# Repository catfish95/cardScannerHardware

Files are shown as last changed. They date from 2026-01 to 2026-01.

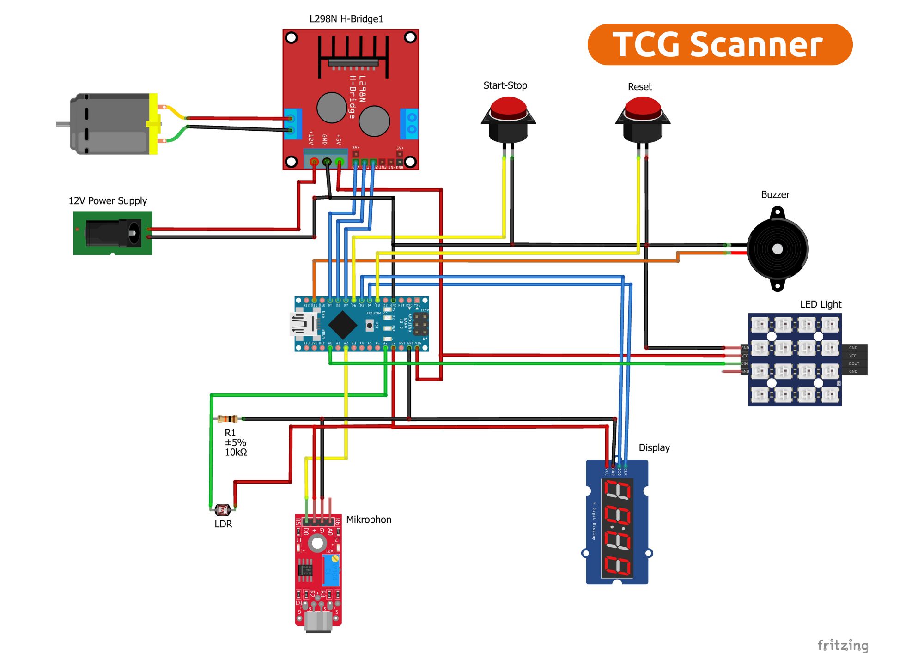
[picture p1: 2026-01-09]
scanner/TCGScanner/Electronics/Wiring diagram - TCG Scanner.jpg

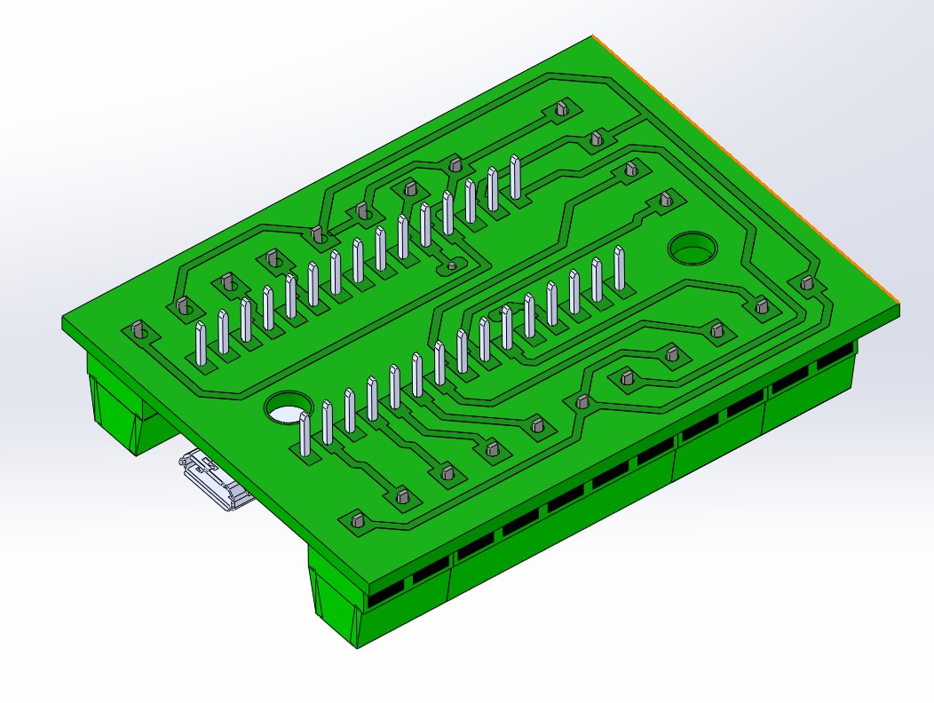
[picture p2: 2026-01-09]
scanner/TCGScanner/Electronics/Picture 2 Circuit board.jpg

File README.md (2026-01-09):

# cardScannerHardware

Hardware documentation and design files for the TCG Card Scanner project.

## Overview

The cardScannerHardware repository contains all the hardware designs, electronics schematics, 3D-printable parts, and Arduino firmware for the TCG Card Scanner automation system.

## Project Structure

### Scanner Hardware (`scanner/TCGScanner/`)

The main scanner hardware project includes:

#### Arduino Code
- **TCG_Card_Scanner_00_English/** - English version of the scanner firmware
- **TCG_Card_Scanner_00_Deutsch/** - German version of the scanner firmware

Key Arduino components:
- Motor control (ENA, IN1, IN2 pins)
- TM1637 7-segment display for card counting
- Adafruit NeoPixel LED ring (8 LEDs) for status indication
- Light sensor (LDR) for card detection
- Buzzer feedback
- Push buttons for manual trigger and reset
- Microphone input for audio feedback

#### Design Files
- **TGC Scanner.DXF** - Technical drawing in DXF format
- **TGC Scanner.PDF** - Portable document version of technical drawings
- **Electronics/** - Electronic schematics and layouts

#### Parts List
- **Part List - TCG Scanner_00.xlsx** - Spreadsheet of required components
- **Part List - TCG Scanner_00.pdf** - PDF version of parts list

#### 3D Printable Components (`STL Files/`)
Complete set of 3D-printable parts including:
- **Structural:** Side panels, side guides, cross connections, light stand
- **Drive System:** Gears, shafts, belt tensioner, rollers, roller holders
- **Card Handling:** Card magazine, card support, retention rollers, outlet guide
- **Electronics Housing:** Gearbox cover, LED holder, light holders, microphone holder
- **Mobile Support:** Smartphone holders (height adjustable), smartphone holder joint
- **Storage:** Side guide storage stacks
- **Hardware Support:** Cable protection, clamping pieces, sleeves

## Hardware Features

- **Automated Card Feeding** - Motor-driven card transport system
- **Card Detection** - Light sensor (LDR) based detection
- **Card Counting** - 7-segment display for real-time count
- **Status Indication** - 8-color NeoPixel LED ring
- **Audio Feedback** - Buzzer for user feedback
- **Mobile Integration** - Adjustable smartphone holders for imaging/processing
- **Configurable Operation** - Multiple startup sequences available

## Building the Scanner

1. Review the part list (Excel or PDF)
2. Obtain all electronic components
3. Print all required STL files (complete list in STL Files directory)
4. Assemble mechanical structure using the technical drawings
5. Wire electronics according to the schematics in Electronics folder
6. Upload Arduino firmware (English or German version) to microcontroller

## Firmware

The Arduino code includes:
- Motor control and PWM management
- Real-time card detection and counting
- LED ring status animations with color fading
- Display brightness dimming
- Button debouncing and timeout handling
- Multiple startup sequences for visual feedback

## Files and Formats

- **DXF/PDF** - For technical drawings and schematics
- **STL** - 3D printable files (printer-ready)
- **XLSX/PDF** - Parts and bill of materials
- **INO** - Arduino firmware code

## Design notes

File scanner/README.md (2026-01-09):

# TCG Card Scanner Hardware

## Overview

This is the TCG Card Scanner hardware project. The scanner is a specialized device designed to automatically scan and identify trading card game (TCG) cards.

## Architecture

The TCG Card Scanner uses a distributed architecture:

- **Raspberry Pi 5**: The main processing unit ("brains") that handles image analysis, card identification, and server communication
- **Raspberry Pi Pico**: Microcontroller for hardware interfacing and control
- **Touch Screen Display**: User interface connected to the Raspberry Pi 5 for card scanning control and feedback
- **Camera Module**: Image capture hardware for scanning cards

## Key Changes from Original Design

The scanner has been redesigned with the following changes from the original version:

1. **Microcontroller Change**: Replaced Arduino with Raspberry Pi Pico for more integrated hardware control
2. **Processing Unit**: Raspberry Pi 5 serves as the main brains, enabling more sophisticated image processing and analysis
3. **Image Capture**: Removed dependency on smartphones for image capture; now uses dedicated camera hardware
4. **User Interface**: Replaced physical buttons (start button, counter, etc.) with a touch screen interface
5. **Server Communication**: Raspberry Pi 5 handles all communication with the backend server

## Hardware Components

### Main Processor
- Raspberry Pi 5

### Microcontroller
- Raspberry Pi Pico

### Input/Output
- Touch Screen Display (connected to RPi 5)
- Dual Camera Module (connected to RPi 5)

### Power & Connectivity
- 12V Power Supply (1A minimum)
- Network connectivity (Ethernet or Wi-Fi) for server communication

### Sensing & Control
- Light Dependent Resistor (LDR) for card position detection
- Microphone module for app trigger detection
- Piezo buzzer for audio feedback
- 7-segment display for card count visualization
- Control buttons (start/stop and reset)

### Lighting
- Neopixel LED ring for optimal card illumination
- 3D-printed diffuser for soft, even lighting

### Mechanical
- Motor for card feeder mechanism
- Motor driver (L298N H-bridge recommended) for motor control
- Card separation mechanism using friction feeder principle

## Directory Structure

```
scanner/
├── README.md                          # This file
├── TCGScanner/
│   ├── TGC Scanner.DXF                # Hardware CAD design file
│   ├── Electronics/                   # Circuit diagrams and schematics
│   │   └── TCG Card Scanner_02.plt    # PCB layout/design
│   ├── STL Files/                     # 3D printable components for physical housing
│   └── Arduino Code/                  # Reference code (legacy, see Pico implementation)
│       ├── TCG_Card_Scanner_00_English/
│       └── TCG_Card_Scanner_00_Deutsch/
```

## Development

### Raspberry Pi Pico Firmware
The RPi Pico firmware handles:
- Hardware initialization and control
- Communication protocol with Raspberry Pi 5
- Real-time sensor and component management

### Raspberry Pi 5 Software
The RPi 5 software includes:
- Image processing and card recognition
- Touch screen interface management
- Server API communication
- Application logic and card database queries

## Hardware Control System

### Control Logic
The Raspberry Pi Pico manages precise control of the card feeding process:

1. **Card Detection**: LDR (Light Dependent Resistor) detects gaps between cards using ambient light changes
2. **Motor Activation**: Triggered by the scanning app via audio signal (microphone module detects tone)
3. **Motion Control**: Motor drives exactly one card forward until the LDR detects the next gap
4. **Automatic Stop**: Motor stops when card gap is detected, preventing multiple-card feeds
5. **Feedback**: Piezo buzzer and LED ring provide visual and audio feedback

### Lighting System
- **Neopixel LED Ring**: Provides optimized illumination for card scanning
- **Dynamic Adjustment**: LEDs dim slightly after card feed if scan doesn't complete, reducing glare and reflections
- **Soft Illumination**: 3D-printed diffuser spreads light evenly, minimizing harsh shadows
- **Color Strategy**: Red light works best for Magic: The Gathering cards (reduces glare on glossy surfaces)

### User Interface Components
- **7-Segment Display**: Shows count of scanned cards in real-time
- **Start/Stop Button**: Pause scanning to make adjustments
- **Reset Button**: Clear card counter and restart
- **Piezo Buzzer**: Audio alerts for errors and system status

## Deployment

The system communicates with the `cardScannerServer` backend for:
- Card identification and database lookup
- User management
- Scanning history and analytics

## 3D Printing

### Print Settings
✅ Infill: 20%
✅ Perimeter: 2 exterior walls
✅ Top and bottom layers: 3

### Material Recommendations
- **Material**: PLA (Polylactic Acid)
- **Color**: White filament (critical for card detection - the scanner app relies on color differentiation between white plastic and card edges)
- **Build Plate Size**: Minimum 220 x 220 mm

### Important Note
White filament is essential throughout the scanner, particularly in the scanning area. The card detection logic depends on distinguishing between the white mechanical components and the colored card edges.

## Card Separation Mechanism

The scanner uses a friction feeder mechanism to ensure reliable single-card separation:

### Principle
- Based on the friction feeding principle (proven design from similar applications)
- Achieves 100% reliability when properly calibrated
- Prevents multiple cards from being fed simultaneously

### Adjuster Roller Setup
The retainer roller controls how tightly cards are held. Proper calibration is essential:

1. **Load first card**: Place one card into the scanner and slide it under the retainer roller
2. **Set light resistance**: Adjust the screw on the retainer roller until you feel very light resistance on the card
3. **Test with second card**: Place a second card on top. It should experience noticeable resistance from the retainer roller
4. **Verify calibration**: Once adjusted correctly, the mechanism feeds exactly one card reliably

## Documentation

- **DXF Design**: CAD file for the physical enclosure (`TGC Scanner.DXF`)
- **Electronics**: Schematic and PCB layout files in the `Electronics/` directory
- **3D Models**: STL files for 3D-printable components in the `STL Files/` directory

## Next Steps

For implementation details, refer to:
1. RPi Pico firmware implementation (to be added)
2. RPi 5 software stack (to be added)
3. Touch screen interface configuration (to be added)
4. Network and server integration guide (to be added)

## License

See LICENSE file in the parent directory for details.

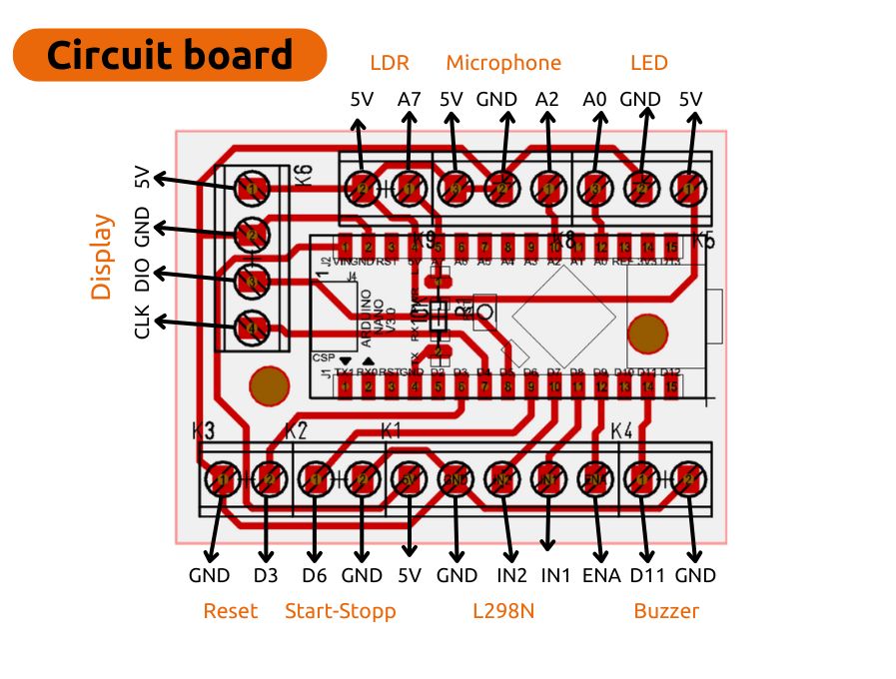
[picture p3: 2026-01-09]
scanner/TCGScanner/Electronics/Circuit board connections.jpg

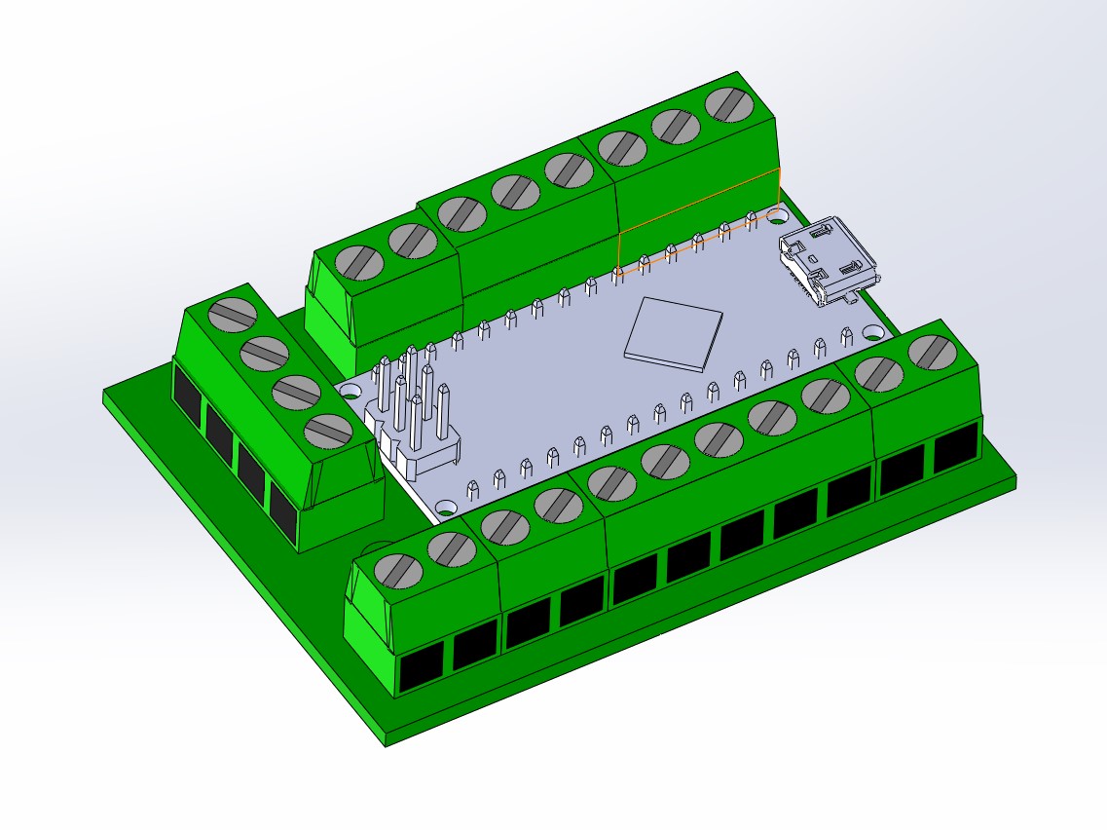
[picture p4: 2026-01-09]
scanner/TCGScanner/Electronics/Picture 1 Circuit board.jpg

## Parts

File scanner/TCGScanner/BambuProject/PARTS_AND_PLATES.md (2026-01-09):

# Card Scanner Hardware - Parts List & Print Plates

This document tracks all components needed for the Card Scanner hardware project, organized by their print plates and suppliers.

## Table of Contents
- [Print Plates Overview](#print-plates-overview)
- [Main Assembly Parts](#main-assembly-parts)
- [Additional Components](#additional-components)
- [Fasteners](#fasteners)

## Print Plates Overview

| Plate | Description | Parts Count | Print Time |
|---|---|---|---|
| Plate 1 | Main structural components | 6 | 4h 19m |
| Plate 2 | Side panels and connections | 5 | 3h 49m |
| Plate 3 | Guide and storage components | 3 | 3h 10m |
| Plate 4 | Cross-connections, covers, retention and clamping | 5 | 3h 26m |
| Optional | Smartphone holders and accessories | 8 | - |
| **Total** | | | **14h 44m** |

---

## Main Assembly Parts

### Structural Components

| Pos. | Naming | Qty | Material | Plate | Notes |
|-----|---|-----|---|---|---|
| 1 | Shaft d=20mm | 2 | PLA/PETG | Plate 1 | Main drive shaft |
| 2 | Counter roller holder | 1 | PLA/PETG | Plate 1 | Holds counter roller |
| 3 | Roller holder left | 1 | PLA/PETG | Plate 1 | Left side roller mount |
| 4 | Shaft for counter roller holder | 1 | PLA/PETG | Plate 1 | Counter roller shaft |
| 5 | Roller holder right | 1 | PLA/PETG | Plate 1 | Right side roller mount |
| 6 | Gear wheel | 2 | PLA/PETG | Plate 1 | Drive gear assembly |
| 7 | Side panel left | 1 | PLA/PETG | Plate 2 | Left enclosure panel |
| 8 | Side panel right | 1 | PLA/PETG | Plate 2 | Right enclosure panel |
| 9 | Cross connection | 1 | PLA/PETG | Plate 2 | Structural cross-brace |
| 10 | Side guide left | 1 | PLA/PETG | Plate 2 | Card guide (left) |
| 11 | Side guide right | 1 | PLA/PETG | Plate 2 | Card guide (right) |
| 12 | Belt tensioner | 2 | PLA/PETG | Plate 2 | Belt tension adjustment |
| 13 | Sleeve 4mm, l=2,8mm | 4 | PLA/PETG | Plate 2 | Spacer sleeves |
| 14 | Side guide storage left | 1 | PLA/PETG | Plate 3 | Storage component |
| 15 | Magazine holder | 1 | PLA/PETG | Plate 3 | Card magazine holder |
| 16 | Card magazine | 1 | PLA/PETG | Plate 3 | Card storage magazine |
| 17 | Smartphone holder 1 | 1 | PLA/PETG | Optional | Phone mount option 1 |
| 18 | Smartphone holder 2 | 1 | PLA/PETG | Optional | Phone mount option 2 |
| 19 | Smartphone holder joint | 1 | PLA/PETG | Optional | Connector for phone holders |
| 20 | Outlet guide | 1 | PLA/PETG | Plate 3 | Card exit guide |
| 21 | Side guide storage stack right | 1 | PLA/PETG | Plate 3 | Right storage component |
| 22 | Rear cross-connection | 1 | PLA/PETG | Plate 4 | Rear structural support |
| 23 | Light stand | 1 | PLA/PETG | Optional | Light mounting bracket |
| 24 | LED holder | 1 | PLA/PETG | Optional | LED mounting bracket |
| 25 | Gearbox cover | 1 | PLA/PETG | Plate 4 | Gear protection cover |
| 26 | Card support | 1 | PLA/PETG | Plate 4 | Card support plate |
| 27 | Cable protection | 1 | PLA/PETG | Plate 4 | Cable management |
| 28 | Smartphone height bar 1 | 1 | PLA/PETG | Optional | Phone height adjustment |
| 29 | Smartphone height bar 2 | 1 | PLA/PETG | Optional | Phone height adjustment |
| 30 | Diffuser | 1 | PLA/PETG | Plate 3 | Light diffuser |
| 31 | Microphone holder | 1 | PLA/PETG | Optional | Microphone mount |
| 32 | Light holder 1 | 1 | PLA/PETG | Optional | Light mounting |
| 33 | Light holder 2 | 1 | PLA/PETG | Optional | Light mounting |
| 34 | Retention roller | 1 | PLA/PETG | Plate 4 | Roller retention clip |
| 35 | Clamping piece | 1 | PLA/PETG | Plate 4 | Clamping mechanism |

### Hardware Components

| Pos. | Naming | Qty | Link |
|-----|---|-----|---|
| 36 | O-Ring d=53.8mm | 10 | https://amzn.to/4h8nPie |
| 37 | Linear guide | 1 | https://amzn.to/415SHkc |
| 38 | Ball bearing 6x8x3 | 4 | https://amzn.to/6t4XEW |
| 39 | Axial geared motor 200rpm, 20mm | 1 | https://amzn.to/43NMJJi |
| 40 | Flex coupling 4mm | 2 | https://amzn.to/6AtATr1 |
| 41 | Compression spring d=5mm, l=20mm, s=0.4mm | 1 | https://amzn.to/4k33Uk6 |
| 42 | O-ring D=18mm, d=2,5mm | 2 | https://amzn.to/61hKn2f |
| 43 | 4mm shaft, l=150mm | 1 | https://amzn.to/41WrRoO |
| 44 | 4mm shaft, l=130mm | 1 | https://amzn.to/41WrRoO |
| 45 | Washer 4mm | 9 | - |
| 46 | Hexagon socket screw M4x16 | 26 | - |
| 47 | Hexagon socket screw M4x20 | 6 | - |
| 48 | Hexagon socket screw M3x10 | 16 | - |
| 49 | Hexagon socket screw M4x10 | 3 | - |
| 50 | Nut M4 | 6 | - |
| 51 | Hexagon socket screw M4x12 | 6 | - |
| 52 | Nut M3 | 2 | - |
| 53 | Hexagon socket screw M3x8 | 5 | - |
| 54 | Hexagon socket screw M3x25 | 1 | - |
| 55 | Nut M6 | 1 | - |
| 56 | Button | 2 | https://amzn.to/3Rd2Lhg |
| 57 | Microphone KY-037 | 1 | https://amzn.to/kky9Hu |
| 58 | LED WS2812B, D=32mm | 1 | https://amzn.to/8lTOgpn |
| 59 | L298N Motor Driver | 1 | https://amzn.to/l7rFCd |
| 60 | Piezo Buzzer KY-012 | 1 | https://amzn.to/6kwS1ws |
| 61 | 7-Segment LED Display | 1 | https://amzn.to/k6o5ycT |
| 62 | DC 1.2V Socket | 1 | https://amzn.to/2bbakNS |

---

## Additional Parts

### Electronics & Power

| Pos. | Naming | Qty | Link |
|-----|---|-----|---|
| 100 | Light-sensitive resistor LDR | 1 | https://amzn.to/6HoHwd9 |
| 110 | Power Supply | 1 | https://amzn.to/43NMTJi |
| 120 | Cables | 1 | https://amzn.to/6tJUGsv |
| 130 | Cables 3 pole | 1 | https://amzn.to/43Pix3L |
| 140 | Arduino Nano | 1 | https://amzn.to/6bDDmtr |
| 150 | 10K Ohm Resistor | 1 | https://amzn.to/kUkyaWs |

### 3D Printing Materials

| Pos. | Naming | Qty | Link | Notes |
|-----|---|-----|---|---|
| 140 | Bambulab X1C | 1 | https://shareasale.com/r.cfm?b=cm/fb=2353821&u=44114728-m=13821 | Primary printer (with link) |
| 150 | Bambulab A1 | 1 | https://shareasale.com/r.cfm?b=cm/fb=2353821&u=44114728-m=13821 | Secondary printer (with link) |
| 160 | Bambulab Filament | 1 | https://shareasale.com/r.cfm?b=cm/fb=2353 730&u=44114728-m=138211 | Filament supply (with link) |

---

## Assembly Notes

### Material Specifications
- **Primary Material:** PLA/PETG (for 3D printed parts)
- **Hardware:** Steel fasteners and shafts
- **Bearings & Motion:** Ball bearings, O-rings, flex couplings

### Plate Layout
- **Plate 1:** Core structural elements (shafts, rollers, gears)
- **Plate 2:** Enclosure and panel components
- **Plate 3:** Magazine and storage systems
- **Plate 4:** External covers, support structures, retention and clamping mechanisms
- **Optional:** Smartphone integration and lighting accessories

### Printing Recommendations
- Use high-quality PLA/PETG filament for durability
- Print at appropriate layer heights for mechanical fit tolerance
- Consider printing support structure parts with reinforcement

---

## Bill of Materials Summary

| Category | Count |
|---|---|
| 3D Printed Parts (Plate 1-5) | 35 |
| Optional/Accessory Parts | 8 |
| Hardware (Bearings, Shafts) | 6 |
| Fasteners (Screws, Bolts, Nuts) | 89+ |
| Electronics | 7 |
| Additional Components | 6 |
| **Total Unique Items** | ~150+ |

---

## Supplier References

### Recommended Suppliers
- **AMAZON (amzn.to):** Individual components and hardware
- **ShareASale:** Bambulab 3D printer partnership links
- **Local Hardware Stores:** Fasteners and standard parts

---

## Version History

| Date | Author | Changes |
|---|---|---|
| 2026-01-08 | Initial | Created comprehensive parts list and plate tracking |

---

## Related Files
- `scanner/TCGScanner/` - Hardware design files
- `scanner/TCGScanner/Arduino Code/` - Microcontroller firmware
- `scanner/TCGScanner/BambuProject/` - 3D printer project files
- `scanner/TCGScanner/STL Files/` - 3D model exports

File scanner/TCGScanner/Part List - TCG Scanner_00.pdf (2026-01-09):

Pos. | Naming | Quantity Material | Link 1 | Shaft d=20mm | 2 PLA/PETG 2 | Counter roller holder | 1 PLA/PETG 3 | Roller holder left | 1 PLA/PETG 4 | Shaft for counterholder roller | 1 PLA/PETG 5 | Roller holder right | 1 PLA/PETG 6 | Gear wheel | 2 PLA/PETG 7 | Side panel left | 1 PLA/PETG 8 | Side panel right | 1 PLA/PETG 9 | Cross connection | 1 PLA/PETG
10 Side guide left | 1 PLA/PETG
11 Side guide right | 1 PLA/PETG
12 Belt tensioner | 2 PLA/PETG
13 Sleeve 4mm, l=2,8mm | 4 PLA/PETG
14 Side guide storage stack | 1 PLA/PETG
15 Magazine holder | 1 PLA/PETG
16 Card magazine | 1 PLA/PETG
17 Smartphone holder 1 | 1 PLA/PETG
18 Smartphone holder 2 | 1 PLA/PETG
19 Smartphone holder joint | 1 PLA/PETG
20 Outlet guide | 1 PLA/PETG
21 Side guide storage stack right | 1 PLA/PETG
22 Rear cross connection | 1 PLA/PETG
23 Light stand | 1 PLA/PETG
24 LED holder | 1 PLA/PETG
25 Gearbox cover | 1 PLA/PETG
26 Card support | 1 PLA/PETG
27 Cable protection | 1 PLA/PETG
28 Smartphone height bar 1 | 1 PLA/PETG
29 Smartphone height bar 2 | 1 PLA/PETG
30 Diffusor | 1 PLA/PETG
31 Microphone holder | 1 PLA/PETG

### Part list Table Loom

32 | Light holder 1 | 1 PLA/PETG
33 | Light holder 2 | 1 PLA/PETG
34 | Retention roller | 1 PLA/PETG
35 | Clamping piece | 1 PLA/PETG
36 | O-Ring d=53,8mm | 10 | https://amzn.to/4hBnPJe
37 | Linear guide | 1 | https://amzn.to/41z5HKc
38 | Ball bearing 4x8x3 | 4 | https://amzn.to/4itAXRW
39 | Axial geared motor 200rpm, 20mm | 1 | https://amzn.to/43NMJlA
40 | Flange coupling 4mm | 2 | https://amzn.to/4kAT0r1
41 | Compression spring d=5mm, l=20mm, s=0,4mm | 1 | https://amzn.to/4kE3UMz
42 | O-ring D=18mm, d=12mm | 2 | https://amzn.to/41KhLZf
43 | 4mm shaft, l=150mm | 1 | https://amzn.to/41WtROO
44 | 4mm shaft, l=130mm | 1 | https://amzn.to/41WtROO
45 | Washer 4mm | 9
46 | Hexagon socket screw M4x16 | 26
47 | Hexagon socket screw M4x20 | 6
48 | Hexagon socket screw M3x10 | 16
49 | Hexagon socket screw M4x10 | 3
50 | Nut M4 | 6
51 | Hexagon socket screw M4x12 | 6
52 | Nut M3 | 2
53 | Hexagon socket screw M3x8 | 5
54 | Hexagon socket screw M6x25 | 1
55 | Nut M6 | 1
56 | Button | 2 | https://amzn.to/3Rd2Lhq
57 | Microphone KY-037 | 1 | https://amzn.to/4ky9NLi
58 | LED WS2812B, D=32mm | 1 | https://amzn.to/4iTOzpn
59 | L298N Motor Driver | 1 | https://amzn.to/4i7FCJd
60 | Piezo Buzzer KY-012 | 1 | https://amzn.to/4kW4Iwe
61 | 7-Segment LED Display | 1 | https://amzn.to/4kxSycY
62 | DC 12V Socket | 1 | https://amzn.to/42bkaNG

### Additional parts

100 | Light-sensitive resistor LDR | 1 | https://amzn.to/4hiodw9
110 | Power Supply | 1 | https://amzn.to/43NMTJI
120 | Cables | 1 | https://amzn.to/4icUGoV
130 | Cables 3 pole | 1 | https://amzn.to/43Pix9L
140 | Arduino Nano | 1 | https://amzn.to/4bDDoir
150 | 10K Ohm Resistor | 1 | https://amzn.to/4kJyaWs
140 | Bambulab X1C | 1 | https://shareasale.com/r.cfm?b=2353821&u=4411472&m=138211&urllink=&afftrack=
150 | Bambulab A1 | 1 | https://shareasale.com/r.cfm?b=2485357&u=4411472&m=138211&urllink=&afftrack=
160 Bambulab Filament | | 1 | https://shareasale.com/r.cfm?b=2354730&u=4411472&m=138211&urllink=&afftrack=

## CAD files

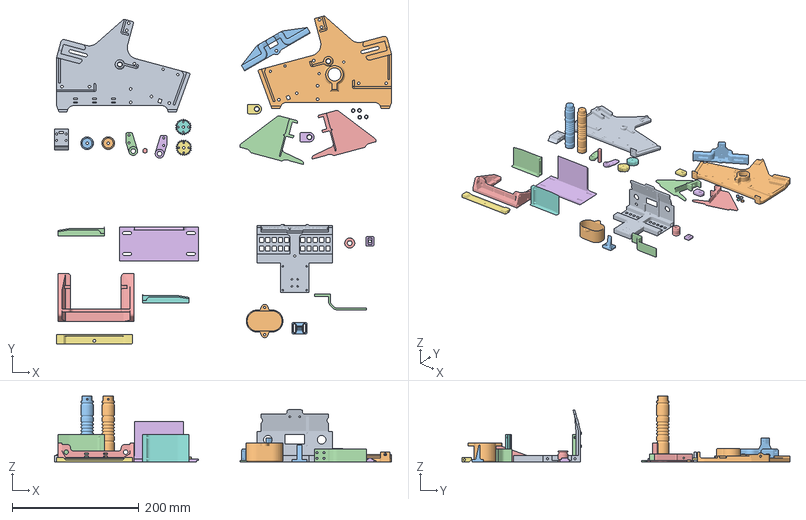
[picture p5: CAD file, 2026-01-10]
scanner/TCGScanner/BambuProject/Card Scanner Project.3mf
533.1 x 518.6 x 104.0 mm
Counter roller holder.STL
Shaft d=20mm.STL x 2
3 - Roller holder left.STL
4 - Shaft for counterholder roller.STL
5 - Roller holder right.STL
6 - Gear wheel.STL x 2
7 - Side panel left.STL
8 - Side panel right.STL
9 - Cross connection.STL
10 -Side guide left.STL
11 - Side guide right.STL
12 - Belt tensioner.STL x 2
13 - Sleeve 4mm, l=2,8mm.STL x 4
14 - Side guide storage stack left.STL
15 - Magazine holder.STL
16 - Card magazine.STL
20 - Outlet guide.STL
21 - Side guide storage stack right.STL
22 - Rear cross connection.STL
25 - Gearbox cover.STL
26 - Card support.STL
27 - .STL
34 - Retention roller.STL
35 - Clamping piece.STL

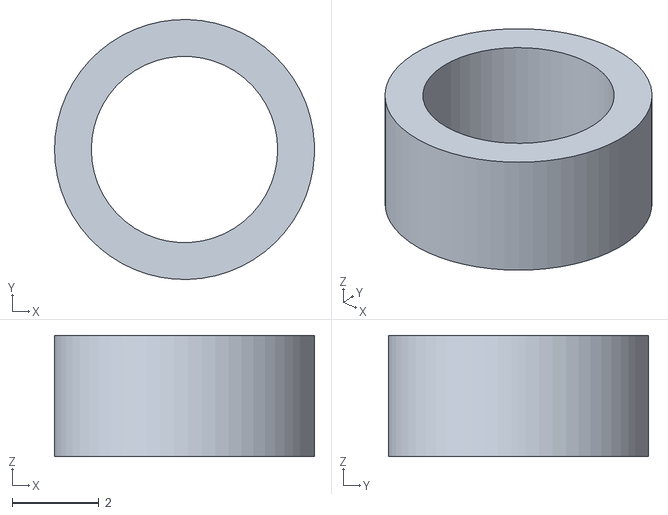
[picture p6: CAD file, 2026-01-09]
scanner/TCGScanner/STL Files/13 - Sleeve 4mm, l=2,8mm.STL
6.00 x 6.00 x 2.80

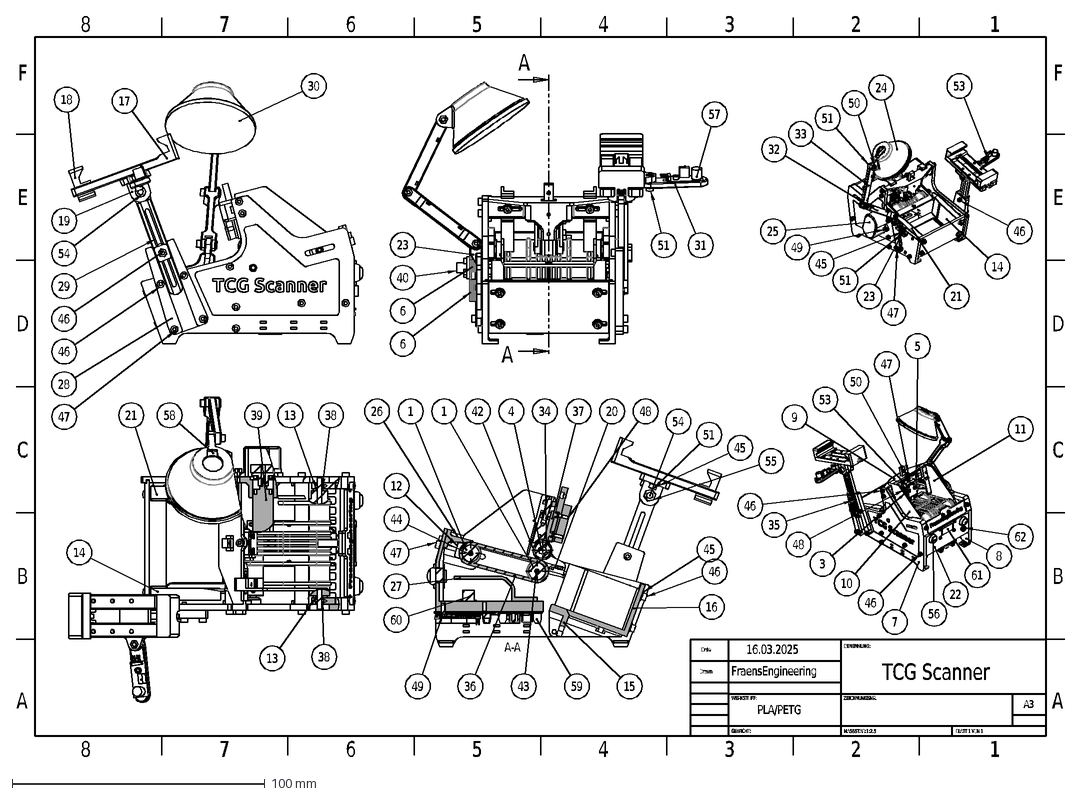
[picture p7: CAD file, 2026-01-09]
scanner/TCGScanner/TGC Scanner.DXF
GEWICHT:
A3
BLATT 1 VON 1
MASSSTAB:1:2.5
TCG Scanner
Drawn
Date
WERKSTOFF:
BENENNUNG:
ZEICHNUNGSNR.
16.03.2025
FraensEngineering
PLA/PETG
A
B
C
D
E
F
8
7
6
5
4
3
2
1
17
18
19
54
28
47
46
29
30
13
21
14
38
39
58
23
31
51
40
57
A-A
12
15
16
45
20
26
27
36
37
48
44
43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

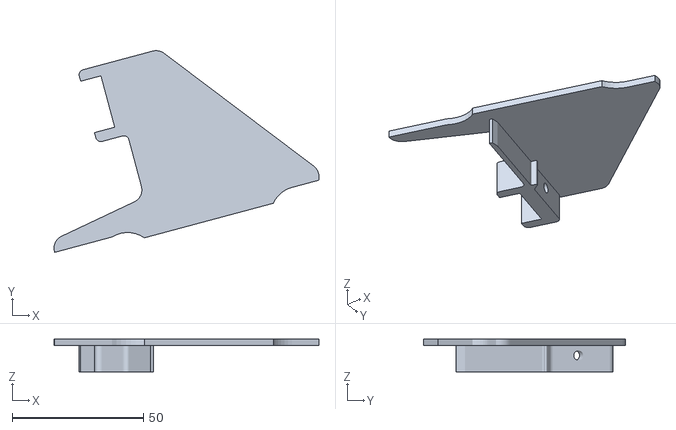
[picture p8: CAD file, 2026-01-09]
scanner/TCGScanner/STL Files/10 -Side guide left.STL
101.1 x 77.0 x 12.5

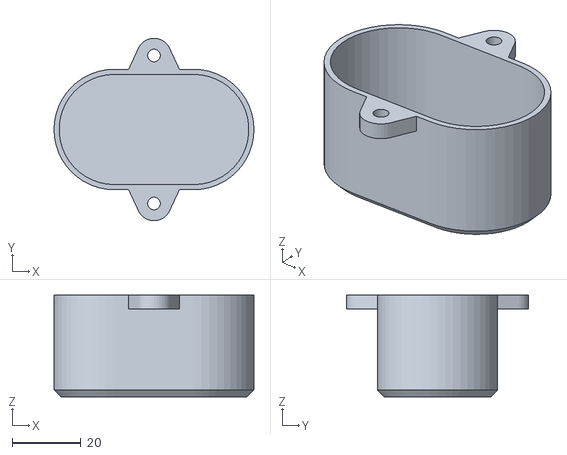
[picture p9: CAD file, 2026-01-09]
scanner/TCGScanner/STL Files/25 - Gearbox cover.STL
58.1 x 53.0 x 29.5

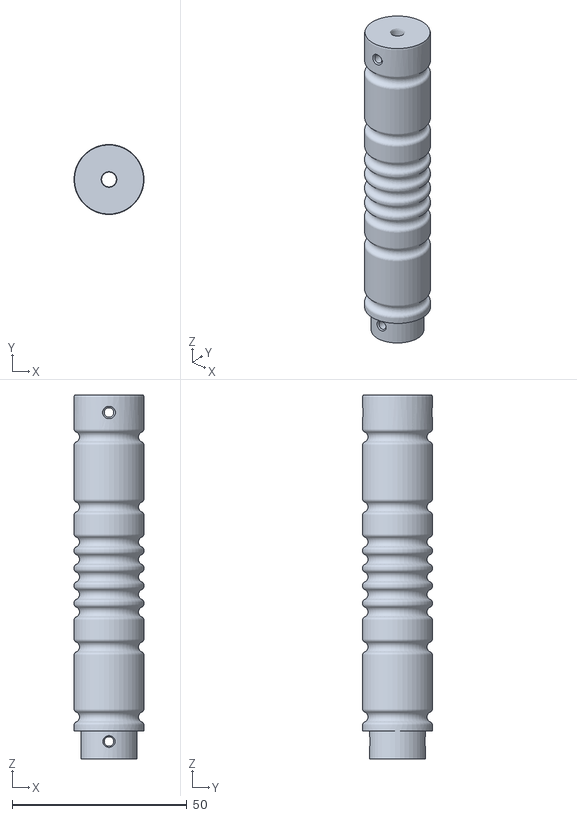
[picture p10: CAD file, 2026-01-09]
scanner/TCGScanner/STL Files/1 - Shaft d=20mm.STL
20.0 x 20.0 x 104.0

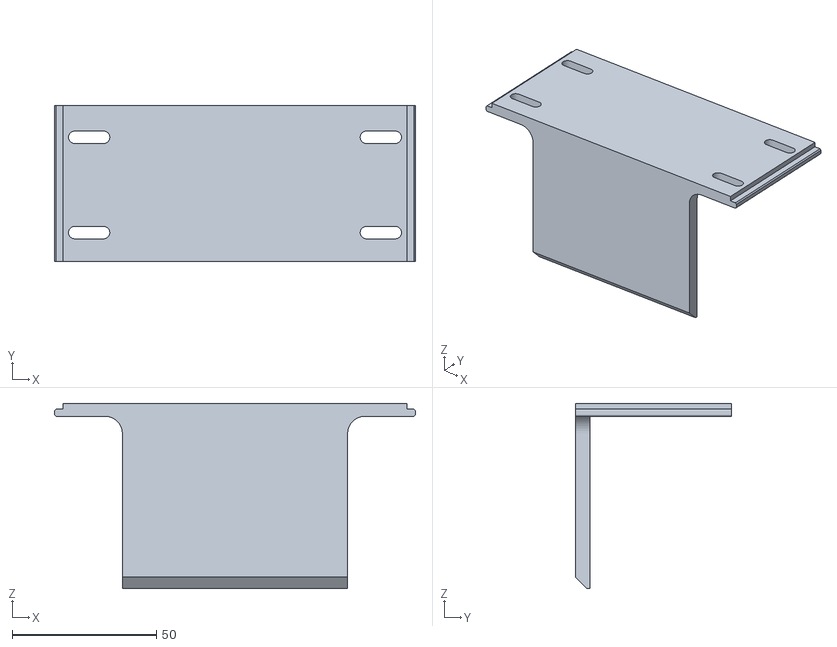
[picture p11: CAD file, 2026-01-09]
scanner/TCGScanner/STL Files/16 - Card magazine.STL
125.0 x 54.0 x 64.2

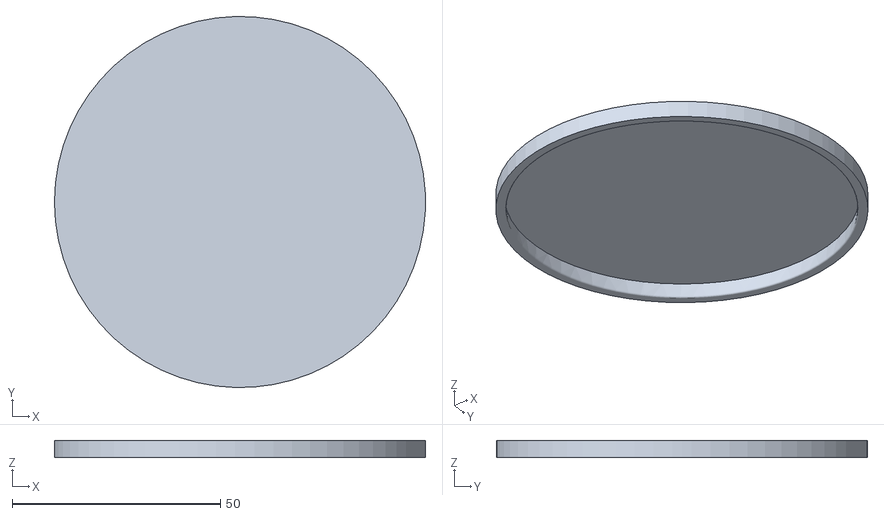
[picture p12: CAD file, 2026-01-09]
scanner/TCGScanner/STL Files/30 - Diffusor.STL
89.1 x 89.1 x 4.20

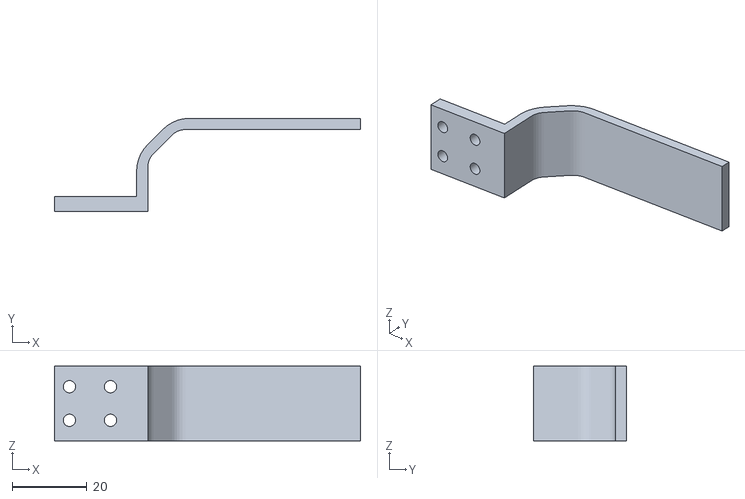
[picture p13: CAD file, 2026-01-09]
scanner/TCGScanner/STL Files/27 - Cable protection.STL
82.0 x 25.0 x 20.0

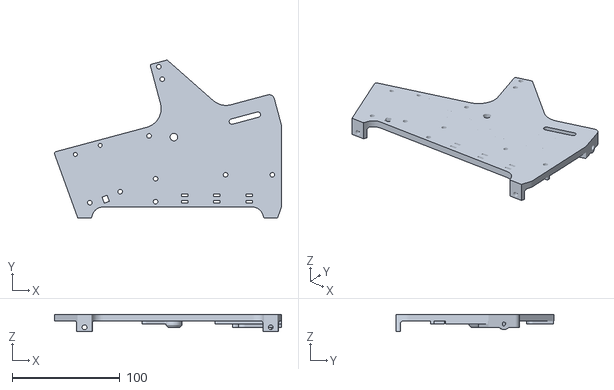
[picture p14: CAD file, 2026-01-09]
scanner/TCGScanner/STL Files/7 - Side panel left.STL
210.9 x 146.5 x 16.0

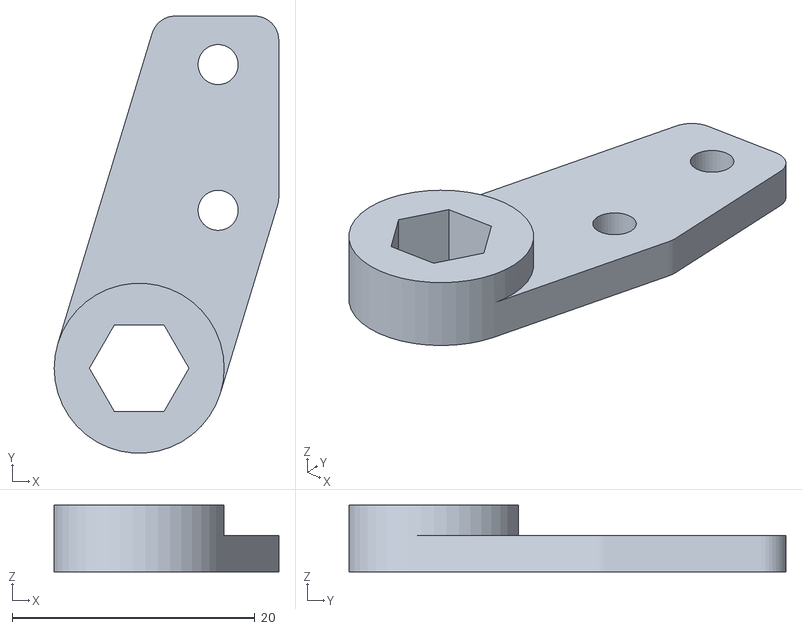
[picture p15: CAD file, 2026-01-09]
scanner/TCGScanner/STL Files/5 - Roller holder right.STL
18.5 x 36.0 x 5.50

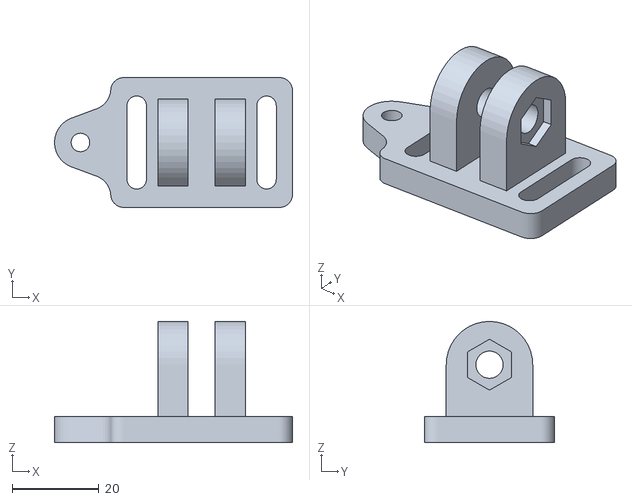
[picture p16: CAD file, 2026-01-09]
scanner/TCGScanner/STL Files/19 - Smartphone holder joint.STL
55.0 x 30.0 x 28.0

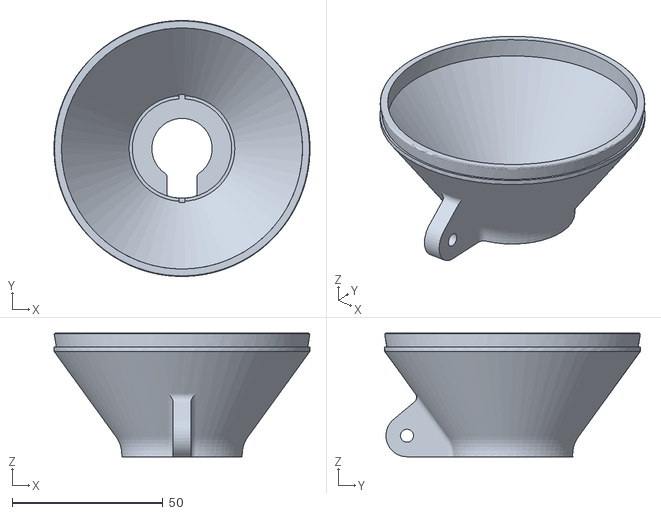
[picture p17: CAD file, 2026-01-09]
scanner/TCGScanner/STL Files/24 - LED holder.STL
84.9 x 84.9 x 41.0

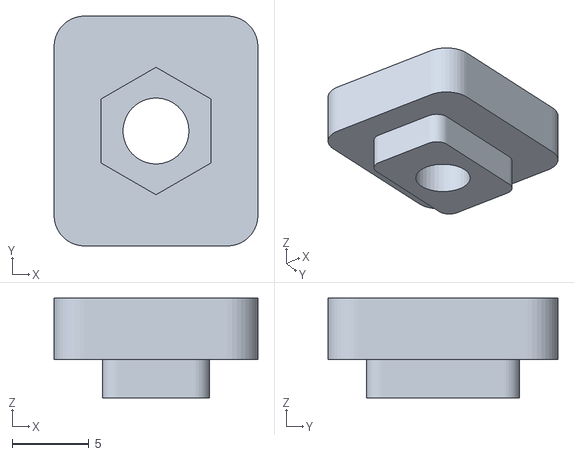
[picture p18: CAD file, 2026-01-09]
scanner/TCGScanner/STL Files/35 - Clamping piece.STL
13.3 x 15.0 x 6.50

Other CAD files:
scanner/TCGScanner/STL Files/3 - Roller holder left.STL
scanner/TCGScanner/STL Files/31 - Microphone holder.STL
scanner/TCGScanner/STL Files/14 - Side guide storage stack left.STL
scanner/TCGScanner/STL Files/11 - Side guide right.STL
scanner/TCGScanner/STL Files/12 - Belt tensioner.STL
scanner/TCGScanner/STL Files/15 - Magazine holder.STL
scanner/TCGScanner/STL Files/17 - Smartphone holder 1.STL
scanner/TCGScanner/STL Files/18 - Smartphone holder 2.STL
scanner/TCGScanner/STL Files/2 - Counter roller holder.STL
scanner/TCGScanner/STL Files/20 - Outlet guide.STL
scanner/TCGScanner/STL Files/21 - Side guide storage stack right.STL
scanner/TCGScanner/STL Files/22 - Rear cross connection.STL
scanner/TCGScanner/STL Files/23 - Light stand.STL
scanner/TCGScanner/STL Files/26 - Card support.STL
scanner/TCGScanner/STL Files/28 - Smartphone height bar 1.STL
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

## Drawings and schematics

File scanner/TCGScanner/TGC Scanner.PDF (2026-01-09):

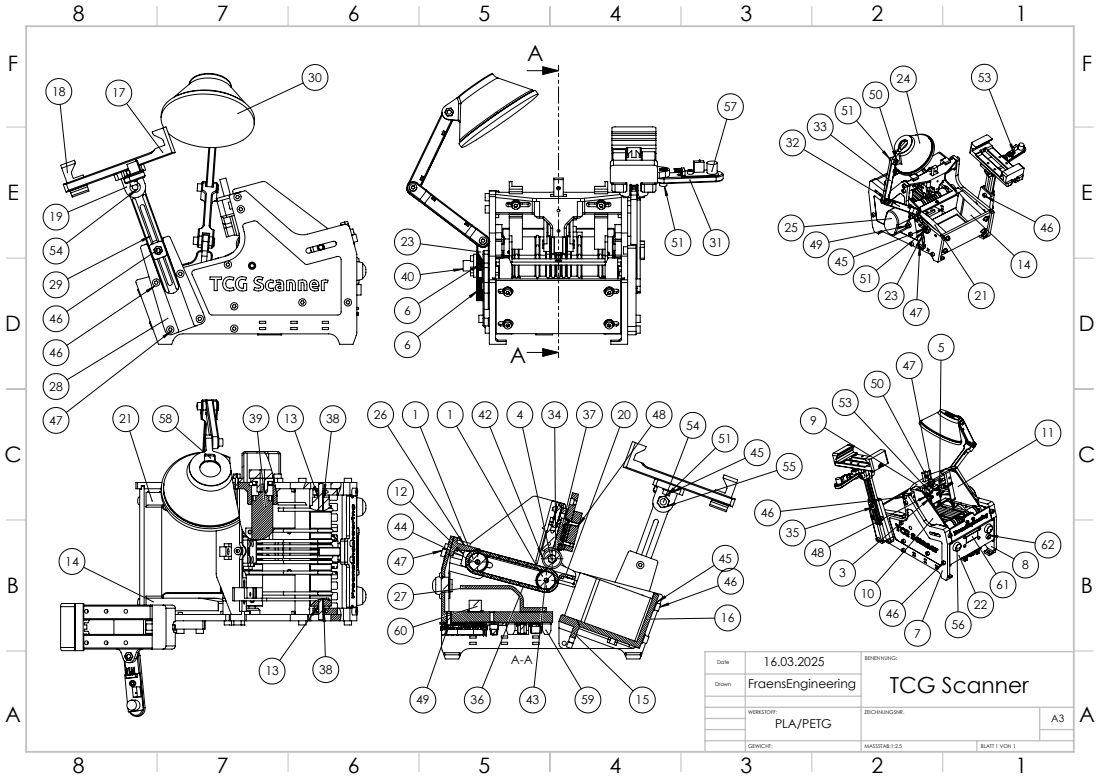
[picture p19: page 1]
MASSSTAB:1:2.5; BLATT 1 VON 1

Date | 16.03.2025 | BENENNUNG:
FraensEngineering | TCG Scanner Drawn

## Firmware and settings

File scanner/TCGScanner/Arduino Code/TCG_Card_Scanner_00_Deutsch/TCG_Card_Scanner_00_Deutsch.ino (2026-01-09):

#include <TM1637Display.h>
#include <Adafruit_NeoPixel.h>

// Pinbelegung
const int ENA = 9;
const int IN1 = 8;
const int IN2 = 7;
const int buzzerPin = 11;
const int ldrPin = A7;
const int buttonResetPin = 3;
const int buttonManualTrigger = 6;
const int micPin = A2;

const int displayClkPin = 4;
const int displayDioPin = 5;

// Display initialisieren
TM1637Display display(displayClkPin, displayDioPin);

// Neopixel-LED initialisieren
Adafruit_NeoPixel ledRing(8, A0, NEO_GRB + NEO_KHZ800);

// Variablen
int cardCount = 0;
bool motorRunning = false;
bool scannerActive = false;
bool cardInPosition = false;
bool timeoutMode = false;
unsigned long lastButtonPress = 0;
unsigned long lastResetPress = 0;
unsigned long lastCardDetectedTime = 0;
unsigned long lastCardMovedTime = 0;
const unsigned long timeoutDuration = 12000;
const unsigned long cardCountDelay = 1000;
unsigned long lastCardCountTime = 0;
int baseLdrValue;

// Lichtsteuerung
const int grundHelligkeit = 255;
unsigned long dimmingStartTime = 0;
const unsigned long dimmingDuration = 5000;
bool isDimmed = false;
unsigned long colorFadeTime = 0;
int fadeStep = 0;

//Startup Sequenz
const int startup = 5;  // Hier kannst du die gewünschte Startsequenz auswählen (1, 2, 3, 4, 5)

void setup() {
  Serial.begin(9600);

  pinMode(ENA, OUTPUT);
  pinMode(IN1, OUTPUT);
  pinMode(IN2, OUTPUT);
  pinMode(buzzerPin, OUTPUT);
  pinMode(buttonResetPin, INPUT_PULLUP);
  pinMode(buttonManualTrigger, INPUT_PULLUP);
  pinMode(ldrPin, INPUT);
  pinMode(micPin, INPUT);

  ledRing.begin();
  setLightRed(grundHelligkeit); // LDR kalibrieren mit rotem Licht
  ledRing.show();

  digitalWrite(ENA, HIGH);
  display.setBrightness(0x0f);
  display.showNumberDec(cardCount);

  delay(500);
  baseLdrValue = analogRead(ldrPin);
  Serial.print("Basis LDR-Wert: ");
  Serial.println(baseLdrValue);
  delay(500);

  // Auswahl der Startsequenz
  switch (startup) {
    case 1:
      startupSequence1();
      break;
    case 2:
      startupSequence2();
      break;
    case 3:
      startupSequence3();
      break;
    case 4:
      startupSequence4();
      break;
    case 5:
      startupSequence5();
      break;
    default:
      Serial.println("Ungültige Startsequenz. Standard wird verwendet.");
      startupSequence1();  // Fallback auf Standardsequenz
      break;
  }
}

void loop() {
  int ldrValue = analogRead(ldrPin);
  Serial.println(ldrValue);
  bool soundDetected = digitalRead(micPin) == HIGH;

  // Startbutton: Umschalten des Scanners
  if (digitalRead(buttonManualTrigger) == LOW) {
    if (millis() - lastButtonPress > 300) {
      scannerActive = !scannerActive;
      lastButtonPress = millis();

      if (scannerActive) {
        setLightRed(255);
        moveCard();
        timeoutMode = false;
        lastCardDetectedTime = millis();
        lastCardMovedTime = millis();
      } else {
        stopMotor();
        timeoutMode = false;
        isDimmed = false;
      }
      ledRing.show();
    }
  }

  // Motorsteuerung
  if (!scannerActive && motorRunning) {
    stopMotor();
  }

  // Reset-Button: Zähler zurücksetzen
  if (digitalRead(buttonResetPin) == LOW && millis() - lastResetPress > 300) {
    cardCount = 0;
    display.showNumberDec(cardCount);
    lastResetPress = millis();
    delay(500);
  }

  // Wenn der Scanner aktiv ist
  if (scannerActive) {
    if (!cardInPosition && ldrValue < baseLdrValue - 50) {
      cardInPosition = true;
      lastCardDetectedTime = millis();
      //Serial.println(cardInPosition);
      //Serial.println("Karte wird gefördert");
      
    }

    if (cardInPosition && ldrValue > baseLdrValue - 30) {
      stopMotor();
      setLightRed(255);
      delay(50);
      baseLdrValue = analogRead(ldrPin);
      cardInPosition = false;
      //Serial.println(cardInPosition);
      //Serial.println("Karte wird gescannt");
    }
    

    if (millis() - lastCardMovedTime >= 3000 && !cardInPosition && !timeoutMode) {
          isDimmed = true;
    }

    if (soundDetected) {
      isDimmed = false;
      setLightRed(255);
      moveCard();
      if (!timeoutMode && millis() - lastCardCountTime > cardCountDelay) {
        lastCardCountTime = millis();
        cardCount++;
        display.showNumberDec(cardCount);

        //Serial.println(cardInPosition);
      }
      lastCardMovedTime = millis();
    }

    if (millis() - lastCardMovedTime > timeoutDuration && !timeoutMode) {
      timeoutMode = true;
      isDimmed = false;
      stopMotor();
      tone(buzzerPin, 1000, 500);
      //Serial.println("Timeout Mode");
    }
  }

  // Timeout-Mode blinkt
  if (timeoutMode) {
    blinkRedLEDAndSoundBuzzer();
  }

  // Pausenmodus - Lichter wechseln sanft
  if (!scannerActive && !timeoutMode) {
    fadeLights();
    //Serial.println("Pause Mode");
  }

  if (isDimmed) {
    //Serial.println(isDimmed);
    dimLights();
  }
}

void moveCard() {
  if (scannerActive && !timeoutMode) {
    digitalWrite(IN1, LOW);
    digitalWrite(IN2, HIGH);
    motorRunning = true;
  }
}

void stopMotor() {
  digitalWrite(IN1, LOW);
  digitalWrite(IN2, LOW);
  motorRunning = false;
}

void blinkRedLEDAndSoundBuzzer() {
  static unsigned long lastBlinkTime = 0;
  unsigned long currentMillis = millis();
  if (currentMillis - lastBlinkTime >= 500) {
    lastBlinkTime = currentMillis;
    static bool ledState = false;
    ledState = !ledState;

    if (ledState) {
      setLightRed(255);
      tone(buzzerPin, 1000, 100);
    } else {
      ledRing.clear();
      noTone(buzzerPin);
    }
    ledRing.show();
  }
}

void dimLights() {
  unsigned long elapsedTime = millis() - dimmingStartTime;  // Berechne die vergangene Zeit seit dem Start des Dimmvorgangs
    // Berechne die Helligkeit basierend auf der verstrichenen Zeit
    int brightness = map(elapsedTime, 0, dimmingDuration, 255, 0);  // Helligkeit von 255 (maximal) auf 0 (minimale Helligkeit) dimmen
    
    // Setze die LEDs auf die berechnete Helligkeit
    setLightRed(brightness);  // Reduziere die Helligkeit der LEDs
  //}

  ledRing.show();  // Setze die LEDs in den aktuellen Zustand
}



void fadeLights() {
  unsigned long currentMillis = millis();
  if (currentMillis - colorFadeTime >= 2000) {  // Farben wechseln alle 2 Sekunden
    colorFadeTime = currentMillis;

    switch (fadeStep % 6) {
      case 0: ledRing.fill(ledRing.Color(255, 0, 0)); break;     // Rot
      case 1: ledRing.fill(ledRing.Color(255, 127, 0)); break;   // Orange
      case 2: ledRing.fill(ledRing.Color(255, 255, 0)); break;   // Gelb
      case 3: ledRing.fill(ledRing.Color(0, 255, 0)); break;     // Grün
      case 4: ledRing.fill(ledRing.Color(0, 0, 255)); break;     // Blau
      case 5: ledRing.fill(ledRing.Color(75, 0, 130)); break;    // Indigo
    }

    ledRing.show();
    fadeStep++;
  }
}

void setLightRed(int brightness) {
  for (int i = 0; i < ledRing.numPixels(); i++) {
    ledRing.setPixelColor(i, ledRing.Color(brightness, 0, 0));
  }
  ledRing.show();
}

void startupSequence1() {
  ledRing.clear();
  ledRing.show();
  
  // Schritt 1: LEDs nacheinander aufleuchten lassen (rot -> grün -> blau -> weiß)
  for (int i = 0; i < ledRing.numPixels(); i++) {
    ledRing.setPixelColor(i, ledRing.Color(255, 0, 0));  // Rot
    ledRing.show();
    tone(buzzerPin, 1000, 100);  // Kurzer Piepton
    delay(100);
  }
  delay(200);

  for (int i = 0; i < ledRing.numPixels(); i++) {
    ledRing.setPixelColor(i, ledRing.Color(0, 255, 0));  // Grün
    ledRing.show();
    tone(buzzerPin, 1200, 100);
    delay(100);
  }
  delay(200);

  for (int i = 0; i < ledRing.numPixels(); i++) {
    ledRing.setPixelColor(i, ledRing.Color(0, 0, 255));  // Blau
    ledRing.show();
    tone(buzzerPin, 1400, 100);
    delay(100);
  }
  delay(200);

  for (int i = 0; i < ledRing.numPixels(); i++) {
    ledRing.setPixelColor(i, ledRing.Color(255, 255, 255));  // Weiß
    ledRing.show();
    tone(buzzerPin, 1600, 100);
    delay(100);
  }
  delay(500);

  // Schritt 2: Alle LEDs kurz blinken lassen
  ledRing.fill(ledRing.Color(255, 255, 255));
  ledRing.show();
  tone(buzzerPin, 2000, 300);
  delay(300);

  ledRing.clear();
  ledRing.show();
  noTone(buzzerPin);
}

void startupSequence2() {
  Serial.println("Starte Startup-Sequenz 4");
  ledRing.clear();
  ledRing.show();

  // Schritt 1: LEDs nacheinander im Kreis aufleuchten lassen
  for (int i = 0; i < ledRing.numPixels(); i++) {
    ledRing.setPixelColor(i, ledRing.Color(255, 165, 0));  // Orange (Warmes Glühen)
    ledRing.show();
    tone(buzzerPin, 800 + (i * 50), 100);  // Steigender Ton pro LED
    delay(100);
  }
  delay(300);

  // Schritt 2: LEDs pulsieren (Hell -> Dunkel -> Hell)
  for (int j = 0; j < 3; j++) {  // 3 Pulszyklen
    for (int brightness = 0; brightness <= 255; brightness += 5) {
      ledRing.fill(ledRing.Color(brightness, brightness / 2, 0));  // Sanftes Orange-Gelb
      ledRing.show();
      delay(10);
    }
    for (int brightness = 255; brightness >= 0; brightness -= 5) {
      ledRing.fill(ledRing.Color(brightness, brightness / 2, 0));
      ledRing.show();
      delay(10);
    }
    tone(buzzerPin, 1200, 150);  // Kurzer Piepton beim Puls
    delay(150);
  }

  // Schritt 3: Blitzartige Animation & Abschluss-Ton
  for (int i = 0; i < 3; i++) {
    ledRing.fill(ledRing.Color(255, 255, 255));  // Weißes Aufblitzen
    ledRing.show();
    tone(buzzerPin, 2000, 100);
    delay(100);

    ledRing.clear();
    ledRing.show();
    noTone(buzzerPin);
    delay(100);
  }

  Serial.println("Startup-Sequenz 4 abgeschlossen!");
}

void startupSequence3() {
  Serial.println("Starte Startup-Sequenz 4");
  ledRing.clear();
  ledRing.show();

  // Schritt 1: Magischer Farbaufbau (Regenbogen-Effekt)
  for (int i = 0; i < ledRing.numPixels(); i++) {
    ledRing.setPixelColor(i, ledRing.Color(255, 0, 255));  // Magenta
    ledRing.show();
    tone(buzzerPin, 800 + (i * 30), 50);  // Steigender Soundeffekt
    delay(50);
  }
  noTone(buzzerPin);
  delay(300);

  // Schritt 2: Wellenartiges Leuchten (von Mitte nach außen)
  int half = ledRing.numPixels() / 2;
  for (int i = 0; i <= half; i++) {
    ledRing.setPixelColor(half - i, ledRing.Color(0, 255, 255));  // Cyan von Mitte nach außen
    ledRing.setPixelColor(half + i, ledRing.Color(0, 255, 255));
    ledRing.show();
    tone(buzzerPin, 1000 + (i * 40), 80);
    delay(80);
  }
  noTone(buzzerPin);
  delay(300);

  // Schritt 3: Pulsierendes Glühen in Blau
  for (int j = 0; j < 3; j++) {
    ledRing.fill(ledRing.Color(0, 0, 255));  // Blau
    ledRing.show();
    tone(buzzerPin, 1500, 100);
    delay(200);

    ledRing.fill(ledRing.Color(0, 0, 100));  // Abdunkeln
    ledRing.show();
    delay(200);
  }
  noTone(buzzerPin);
  delay(300);

  // Schritt 4: Schnell rotierende LEDs + finaler Scan-Ton
  for (int i = 0; i < ledRing.numPixels(); i++) {
    ledRing.setPixelColor(i, ledRing.Color(255, 255, 255));  // Weißer Lichtbogen
    ledRing.setPixelColor((i + ledRing.numPixels() / 2) % ledRing.numPixels(), 0);
    ledRing.show();
    tone(buzzerPin, 2000 + (i * 20), 30);
    delay(30);
  }
  noTone(buzzerPin);
  delay(300);

  // Abschlussblitz
  ledRing.fill(ledRing.Color(255, 255, 255));
  ledRing.show();
  tone(buzzerPin, 2500, 150);
  delay(150);
  ledRing.clear();
  ledRing.show();
  noTone(buzzerPin);

  Serial.println("Startup-Sequenz 4 abgeschlossen!");
}


void startupSequence4() {
  Serial.println("Starte Startup-Sequenz 4");
  ledRing.clear();
  ledRing.show();

  // Schritt 1: Magischer Farbaufbau (Regenbogen-Effekt)
  for (int i = 0; i < ledRing.numPixels(); i++) {
    ledRing.setPixelColor(i, ledRing.Color(255, 0, 255));  // Magenta
    ledRing.show();
    tone(buzzerPin, 800 + (i * 30), 50);  // Steigender Soundeffekt
    delay(50);
  }
  noTone(buzzerPin);
  delay(300);

  // Schritt 2: Wellenartiges Leuchten (von Mitte nach außen)
  int half = ledRing.numPixels() / 2;
  for (int i = 0; i <= half; i++) {
    ledRing.setPixelColor(half - i, ledRing.Color(0, 255, 255));  // Cyan von Mitte nach außen
    ledRing.setPixelColor(half + i, ledRing.Color(0, 255, 255));
    ledRing.show();
    tone(buzzerPin, 1000 + (i * 40), 80);
    delay(80);
  }
  noTone(buzzerPin);
  delay(300);

  // Schritt 3: Pulsierendes Glühen in Blau
  for (int j = 0; j < 3; j++) {
    ledRing.fill(ledRing.Color(0, 0, 255));  // Blau
    ledRing.show();
    tone(buzzerPin, 1500, 100);
    delay(200);

    ledRing.fill(ledRing.Color(0, 0, 100));  // Abdunkeln
    ledRing.show();
    delay(200);
  }
  noTone(buzzerPin);
  delay(300);

  // Schritt 4: Schnell rotierende LEDs + finaler Scan-Ton
  for (int i = 0; i < ledRing.numPixels(); i++) {
    ledRing.setPixelColor(i, ledRing.Color(255, 255, 255));  // Weißer Lichtbogen
    ledRing.setPixelColor((i + ledRing.numPixels() / 2) % ledRing.numPixels(), 0);
    ledRing.show();
    tone(buzzerPin, 2000 + (i * 20), 30);
    delay(30);
  }
  noTone(buzzerPin);
  delay(300);

  // Abschlussblitz
  ledRing.fill(ledRing.Color(255, 255, 255));
  ledRing.show();
  tone(buzzerPin, 2500, 150);
  delay(150);
  ledRing.clear();
  ledRing.show();
  noTone(buzzerPin);

  Serial.println("Startup-Sequenz 4 abgeschlossen!");
}


void startupSequence5() {
  Serial.println("Starte Startup-Sequenz 5");
  ledRing.clear();
  ledRing.show();

  // Schritt 1: Schnelles LED-Laufen im Uhrzeigersinn (Scan-Start)
  for (int i = 0; i < ledRing.numPixels(); i++) {
    ledRing.setPixelColor(i, ledRing.Color(0, 0, 255));  // Blau
    ledRing.show();
    tone(buzzerPin, 800 + (i * 20), 50);  // Steigender Soundeffekt
    delay(50);
    ledRing.setPixelColor(i, 0);  // LED sofort wieder aus
  }
  noTone(buzzerPin);
  delay(300);

  // Schritt 2: Ladeanimation von außen zur Mitte (Energieaufbau)
  int half = ledRing.numPixels() / 2;
  for (int i = half; i >= 0; i--) {
    ledRing.setPixelColor(half - i, ledRing.Color(255, 255, 0));  // Gelb von außen nach innen
    ledRing.setPixelColor(half + i, ledRing.Color(255, 255, 0));  
    ledRing.show();
    tone(buzzerPin, 1000 + (i * 50), 50);
    delay(80);
  }
  noTone(buzzerPin);
  delay(300);

  // Schritt 3: Kurzes weißes Pulsieren (geladen)
  for (int j = 0; j < 3; j++) {
    ledRing.fill(ledRing.Color(255, 255, 255));  // Weiß blinkt
    ledRing.show();
    tone(buzzerPin, 1500, 100);
    delay(200);

    ledRing.clear();
    ledRing.show();
    delay(200);
  }
  noTone(buzzerPin);
  delay(300);

  // Schritt 4: Explosionsartiges Entladen von der Mitte nach außen
  for (int i = 0; i <= half; i++) {
    ledRing.setPixelColor(half - i, 0);  // LEDs erlöschen von innen nach außen
    ledRing.setPixelColor(half + i, 0);
    ledRing.show();
    tone(buzzerPin, 2000 - (i * 50), 50);  // Abfallender Ton
    delay(80);
  }
  noTone(buzzerPin);
  delay(300);

  // Letzter Scan-Blitz + Sound
  for (int i = 0; i < 2; i++) {
    ledRing.fill(ledRing.Color(255, 0, 0));  // Rotes Aufblitzen
    ledRing.show();
    tone(buzzerPin, 2500, 150);
    delay(150);

    ledRing.clear();
    ledRing.show();
    noTone(buzzerPin);
    delay(150);
  }

  Serial.println("Startup-Sequenz 5 abgeschlossen!");
}

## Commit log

2026-01-09 init with stl files
    [Belt tensioner.STL, Cable protection.STL, Card magazine.STL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]
2026-01-09 organized print files, added parts and plates for bambu printing
    [1 - Shaft d=20mm.STL, 10 -Side guide left.STL, 11 - Side guide right.STL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]
2026-01-10 updated 3mf file to not overflow printing board
    [Card Scanner Project.3mf]
